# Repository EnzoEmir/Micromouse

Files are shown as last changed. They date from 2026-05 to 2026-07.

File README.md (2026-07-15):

# Micromouse — PI1 2026.1, Grupo 02

Projeto desenvolvido para a disciplina Projeto Integrador 1 (PI1) da FCTE/UnB. O desafio proposto pelos professores: projetar e construir, em equipes de até 20 integrantes, um robô Micromouse capaz de resolver labirintos 4x4 e 8x8 de forma **totalmente autônoma**, sem intervenção humana durante a corrida.

## O desafio

- Labirintos 4x4 e 8x8, com configuração de paredes definida pelos professores no dia da competição.
- Ponto de largada em um canto do labirinto, sorteado no momento da corrida.
- Cada célula do labirinto mede 18 cm de lado, com paredes de 1,2 cm de espessura.
- O objetivo é um bloco de 4 células (2x2) sem paredes entre si, no centro do labirinto.
- O robô precisa mapear o labirinto, alcançar esse bloco central e, em seguida, percorrê-lo pelo caminho mais curto conhecido.

## Estrutura do repositório

O projeto foi dividido em quatro núcleos: Eletrônica, Software, Estrutura e Energia. A organização de pastas segue o [template padrão do PI1](https://github.com/fcte-pi1/template):

| Pasta | Conteúdo |
|---|---|
| [`src/firmware`](src/firmware) | Firmware do Micromouse (ESP32/ESP-IDF): navegação, resolução de labirinto, controle de motores e sensores. |
| [`src/backend`](src/backend) | API (FastAPI) que recebe a telemetria do robô e persiste o histórico das corridas. |
| [`src/frontend`](src/frontend) | Interface web (React) para acompanhar o robô em tempo real durante a corrida. |
| [`hw`](hw) | Esquemáticos, PCBs e datasheets dos componentes eletrônicos. |
| [`mec`](mec) | Modelagem 3D, desenhos técnicos e montagem do chassi e do labirinto. |
| [`docs`](docs) | Documentação do projeto: EAP, relatório técnico, análise de riscos e seleção de componentes. |

## Minha participação

Atuei como **gerente de projeto** e como membro do **núcleo de Eletrônica**, focado no firmware do robô. Minhas principais responsabilidades técnicas foram:

- Firmware de navegação e resolução de labirinto (algoritmo flood-fill), em `src/firmware`.
- Calibração dos sensores (ToF, giroscópio/IMU, encoders) usados na navegação.
- Comunicação do robô com o sistema web (telemetria via Wi-Fi/HTTP durante a corrida).

Como gerente de projeto, coordenei a comunicação entre os quatro núcleos (Eletrônica, Software, Estrutura e Energia), priorizando e sincronizando as atividades que dependiam de mais de um núcleo para reduzir gargalos entre as equipes.

## Fluxo de execução do firmware

O `app_main` do firmware (`teste_navegacao.cpp`) segue, em cada corrida, a seguinte sequência:

1. **Inicialização de hardware** — sobe o barramento I2C (bateria/INA226), inicializa os 3 sensores ToF usados (frontal, esquerda, direita), o giroscópio (MPU9250), os encoders (via PCNT) e os motores. A conexão Wi-Fi é disparada em background, sem bloquear o boot.
2. **Seleção de largada** — com o robô parado, toques curtos no botão único alternam entre as combinações de tamanho do labirinto (4x4/8x8) e lado de largada (esquerda/direita); segurar o botão (≥ 0,7 s) confirma a seleção, calibra o bias do giroscópio e dá a largada.
3. **Envio da configuração inicial e heartbeat** — envia o pacote de configuração (tipo 0) ao backend, se o Wi-Fi já estiver conectado, e inicia uma tarefa paralela que envia heartbeats (tipo 4) periodicamente até o fim da execução.
4. **Mapeamento** — a cada célula, lê as paredes com os sensores ToF e avança um passo da máquina de estados do labirinto (flood-fill), que decide a direção e aciona os comandos de giro/avanço do robô. Cada nova célula descoberta é reportada ao backend (tipo 1). O mapeamento só termina após visitar todas as células alcançáveis do bloco 2x2 central (confirmando que o objetivo está aberto e foi de fato alcançado) ou, em caso de bloqueio, envia o pacote de fim de corrida (tipo 3) com falha.
5. **Corrida rápida (fast run)** — após o mapeamento, o robô é reposicionado manualmente na largada; um novo aperto do botão envia a rota ótima calculada (tipo 2) e inicia a corrida rápida, que percorre o labirinto pelo caminho mais curto conhecido, otimizando trechos retos em uma única execução contínua. Ao concluir, envia o pacote de fim de corrida (tipo 3) com sucesso e a velocidade média.
6. **Monitoramento contínuo** — em paralelo às fases acima, a temperatura é verificada a cada passo; se ultrapassar o limiar crítico, a corrida é abortada, os motores são parados e os pacotes de alerta (tipo 5) e fim de corrida (tipo 3, sem sucesso) são enviados.

## Demonstração

Vídeo da execução completa no labirinto 8x8: https://youtu.be/1a2v_xoSXcU

<p>
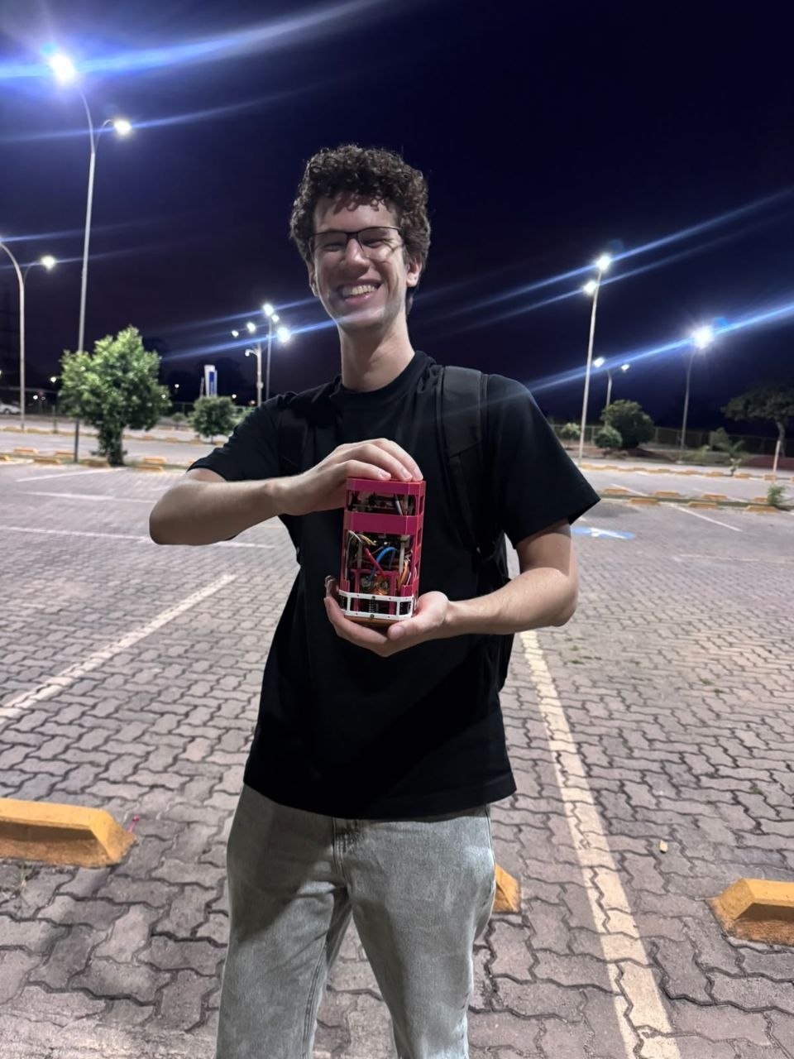
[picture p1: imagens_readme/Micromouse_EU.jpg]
Eu segurando o Micromouse
  
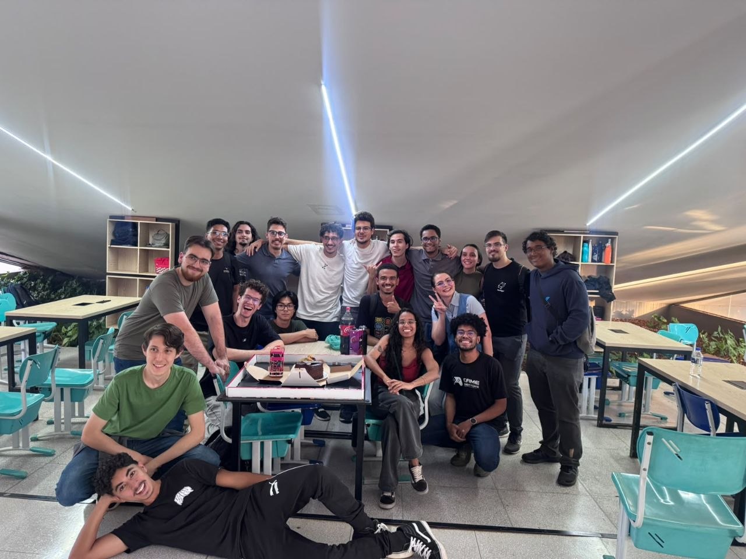
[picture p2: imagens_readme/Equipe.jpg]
Equipe do projeto
  
</p>

## Sobre este fork

Este repositório é um fork do projeto original de equipe, mantido para referência pessoal do trabalho realizado. Mais detalhes sobre a implementação do firmware estão em [`src/firmware`](src/firmware).

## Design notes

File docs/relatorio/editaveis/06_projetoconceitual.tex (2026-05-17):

\chapter{Projeto Conceitual do Produto}

\section{Características gerais}

\textcolor{red}{Descrever produto de forma geral. Apresentar itens teóricos sobre o projeto a serem aprofundados ou detalhados oportunamente.}

\textcolor{red}{Apresentar e explicar a Estrutura Analítica do Projeto (EAP), tomando cuidado com a legibilidade da imagem. Se necessário, coloque a EAP dentro do comando ``\textsf{\textbackslash begin\{landscape\} \textbackslash end\{landscape\}}'' para que ela seja apresentada em uma página deitada.}

\section{Estrutura}

\textcolor{red}{Apresentar desenho em CAD, indicar dimensões por lado/aresta/cota, indicar materiais utilizados e explicar o desenho e as decisões de projeto.}

\section{Descrição de \textit{hardware}}

\textcolor{red}{A descrição de \textit{hardware} no documento deve permitir que outras pessoas repliquem o produto proposto neste documento. Para isso, deve-se explicar de forma textual os principais sub-sistemas e as escolhas de projeto, além de indicar:}

\begin{itemize}
    \item \textcolor{red}{ O diagrama de blocos \cite{blockdiagram}, que oferece uma visão geral do hardware, com as principais partes do sistema e as ligações entre elas.}
    %\item A lista de materiais \cite{bom}, que facilita a montagem do sistema, indicando tudo que deve ser adquirido. Aproveitem a lista de materiais para apresentarem o orçamento dos mesmos.
    \item \textcolor{red}{ O esquemático \cite{esquematico}, que mostra as conexões elétricas entre os componentes. Deve-se indicar os componentes por nomes e símbolos, e as conexões entre eles, incluindo a pinagem dos componentes. Se o esquemático ficar muito grande, pode-se separa-lo em vários esquemáticos. A ligação em \textit{protoboard} não é considerada um esquemático adequado.}
\end{itemize}

\textcolor{red}{A Fig. \ref{fig:diagrama_blocos_e_esquematico} apresenta o diagrama de blocos e o esquemático de um circuito conversor de corrente alternada para corrente direta, a título de exemplo. Repare que o diagrama de blocos indica os subsistemas do circuito completo apresentado no esquemático.
% Comecem com o diagrama de blocos, que é mais genérico, e depois indiquem os detalhes com a lista de materiais e os esquemáticos.
}

\begin{figure}
    \centering
    
    
    \caption{\textcolor{red}{Diagrama de blocos e esquemático de um circuito conversor de corrente alternada para corrente direta. Extraído de \cite{block_n_schematic}.}}
    \label{fig:diagrama_blocos_e_esquematico}
\end{figure}

\section{Análise de consumo energético}

\subsection{Identificação dos Subsistemas Elétricos}
\label{sec:identificacao_subsistemas}

A identificação dos subsistemas elétricos foi realizada com base nos componentes que consumirão energia durante a operação do micromouse, incluindo sensores, microcontroladores, atuadores, módulos de armazenamento e circuitos de suporte. Para fins de dimensionamento, foi adotado um tempo estimado de uso de 7200\,s, correspondente a uma missão de aproximadamente 2 horas. Os valores de tensão e corrente média foram obtidos a partir de \textit{datasheets} sempre que disponíveis, ou por estimativas conservadoras baseadas em condições realistas de operação.

\begin{table}[htbp]
    \centering
    \caption{Identificação dos subsistemas elétricos e parâmetros de operação}
    \label{tab:subsistemas_eletricos}

    \renewcommand{\arraystretch}{1.2}

    \begin{tabular}{lcccc}
        \hline
        \textbf{Componente} &
        \textbf{Qtde} &
        \textbf{Tensão (V)} &
        \textbf{Corrente média (mA)} &
        \textbf{Tempo (s)} \\
        \hline

        ESP32 & 1 & 3,3 & 200 & 7200 \\
        VL53L0X & 6 & 3,3 & 20 & 7200 \\
        Motor N20 (6V) & 2 & 6,0 & 400 & 7200 \\
        Driver (TB6612) & 1 & 3,3 & 30 & 7200 \\
        MPU6050 & 1 & 3,3 & 4 & 7200 \\
        INA226 & 1 & 3,3 & 0,33 & 7200 \\
        SD Reader & 1 & 3,3 & 80 & 7200 \\
        Regulador (MP1584EN) & 1 & 3,3 & 100 & 7200 \\
        Outros (LEDs, perdas) & -- & 3,3 & 100 & 7200 \\

        \hline
    \end{tabular}
\end{table}

Os valores apresentados na Tabela~\ref{tab:subsistemas_eletricos} contemplam os principais elementos energizados do sistema.

\subsection{Cálculo da Energia Consumida por Componente}
\label{sec:calculo_energia_componente}

A energia consumida por cada componente foi calculada por meio da expressão:

\begin{equation}
E = V \cdot I \cdot t
\end{equation}

em que $E$ representa a energia em joules, $V$ a tensão em volts, $I$ a corrente em ampères e $t$ o tempo de uso em segundos. Para os cálculos, as correntes em miliampères foram convertidas para ampères.

A seguir, apresenta-se o detalhamento da energia consumida por cada subsistema, cujos valores estão sintetizados na Tabela~\ref{tab:energia_por_componente}.

\begin{table}[htbp]
    \centering
    \caption{Energia consumida por componente}
    \label{tab:energia_por_componente}

    \renewcommand{\arraystretch}{1.2}

    \begin{tabular}{lc}
        \hline
        \textbf{Componente} & \textbf{Energia (J)} \\
        \hline

        ESP32 & 4752,00 \\
        VL53L0X & 2851,20 \\
        Motor N20 (2 unidades) & 34560,00 \\
        Driver (TB6612) & 712,80 \\
        MPU6050 & 95,04 \\
        INA226 & 7,84 \\
        SD Reader & 1900,80 \\
        Regulador (MP1584EN) & 2376,00 \\
        Outros (LEDs, perdas) & 2376,00 \\

        \hline
        \textbf{Total} & \textbf{49631,68} \\
        \hline
    \end{tabular}
\end{table}

\subsection{Estimativa do Consumo Total de Energia}
\label{sec:consumo_total_energia}

A energia total estimada por lançamento corresponde à soma das energias individuais dos subsistemas listados anteriormente:

\begin{equation}
E_{\text{total}}
=
4752{,}00 + 2851{,}20 + 34560{,}00 + 712{,}80 + 95{,}04 + 7{,}84 + 1900{,}80 + 2376{,}00 + 2376{,}00
\end{equation}

\begin{equation}
E_{\text{total}}
=
49631{,}68\,\mathrm{J}
\end{equation}

Para expressar esse consumo em watt-hora, utiliza-se a relação:

\begin{equation}
1\,\mathrm{Wh} = 3600\,\mathrm{J}
\end{equation}

Logo, a conversão do consumo total é dada por:

\begin{equation}
E_{\text{total,Wh}}
=
\frac{49631{,}68}{3600}
\approx
13{,}79\,\mathrm{Wh}
\end{equation}

Também é possível estimar a corrente média total do sistema a partir da soma das correntes nominais:

\begin{equation}
I_{\text{nom}}
=
200 + 120 + 800 + 30 + 4 + 0{,}33 + 80 + 100 + 100
=
1434{,}33\,\mathrm{mA}
\end{equation}

Portanto,

\begin{equation}
I_{\text{nom}}
\approx
1{,}434\,\mathrm{A}
\end{equation}

Para tornar o dimensionamento mais robusto, foi aplicada uma margem de segurança de 40\%, a fim de contemplar variações de carga, perdas não modeladas e oscilações durante a operação:

\begin{equation}
I_{\text{proj}}
=
I_{\text{nom}} \times 1{,}4
\end{equation}

Substituindo-se o valor obtido:

\begin{equation}
I_{\text{proj}}
=
1{,}434 \times 1{,}4
\approx
2{,}01\,\mathrm{A}
\end{equation}

Em seguida, considerou-se um fator de utilização de 70\%, uma vez que nem todos os subsistemas operam continuamente em máxima corrente durante toda a missão:

\begin{equation}
I_{\text{real}}
=
I_{\text{proj}} \times 0{,}7
\end{equation}

Assim,

\begin{equation}
I_{\text{real}}
=
2{,}01 \times 0{,}7
\approx
1{,}41\,\mathrm{A}
\end{equation}

A capacidade mínima da bateria pode ser estimada por:

\begin{equation}
C_{\text{min}}
=
I_{\text{real}} \times t
\end{equation}

Para uma autonomia de 2 horas:

\begin{equation}
C_{\text{min}}
=
1{,}41 \times 2
=
2{,}82\,\mathrm{Ah}
\approx
2820\,\mathrm{mAh}
\end{equation}

Para uma autonomia de 3 horas:

\begin{equation}
C_{\text{min}}
=
1{,}41 \times 3
=
4{,}23\,\mathrm{Ah}
\approx
4230\,\mathrm{mAh}
\end{equation}

\subsection{Escolha da Fonte de Alimentação}
\label{sec:escolha_fonte}

Com base no consumo energético total estimado, a demanda por lançamento é de aproximadamente 13,79\,Wh. Considerando uma margem de segurança adicional de 25\%, obtém-se uma demanda projetada de aproximadamente 17,24\,Wh.

\begin{equation}
E_{\text{proj,Wh}}
=
13{,}79 \times 1{,}25
\approx
17{,}24\,\mathrm{Wh}
\end{equation}

A fonte de alimentação selecionada é um conjunto formado por duas células idênticas em série do modelo N21700CG-50 da BAK Battery. Considerando as especificações típicas informadas, cada célula possui tensão nominal de 3,6\,V e capacidade de 5,0\,Ah. Em série, o conjunto passa a fornecer tensão nominal de 7,2\,V, mantendo a capacidade de 5,0\,Ah.

A energia nominal do conjunto é dada por:

\begin{equation}
E_{\text{bat}}
=
7{,}2 \times 5{,}0
=
36\,\mathrm{Wh}
\end{equation}

Esse valor é superior à demanda projetada de 17,24\,Wh, oferecendo folga energética suficiente para o funcionamento do robô.

Como os motores são nominais de 6\,V, o barramento principal será tratado como a alimentação de potência do sistema, enquanto os blocos de lógica, sensores e microcontrolador serão alimentados com tensão regulada pelo MP1584EN para 3,3\,V.

A tabela a seguir resume a escolha da fonte.

\begin{table}[htbp]
    \centering
    \caption{Resumo da fonte de alimentação selecionada}
    \label{tab:fonte_alimentacao}

    \renewcommand{\arraystretch}{1.2}

    \begin{tabular}{lccc}
        \hline
        \textbf{Fonte} & \textbf{Tensão nominal} & \textbf{Capacidade} & \textbf{Energia} \\
        \hline
        2 células em série & 7,2\,V & 5,0\,Ah & 36\,Wh \\
        \hline
    \end{tabular}
\end{table}

subsubsection{Síntese do dimensionamento}

Com base nos cálculos apresentados, o sistema possui consumo energético estimado de 49\,631,68\,J por lançamento, equivalente a aproximadamente 13,79\,Wh. Após aplicação de margem de segurança de 25\%, a demanda projetada passa a ser de aproximadamente 17,24\,Wh.

A fonte selecionada, composta por duas células em série, fornece aproximadamente 36\,Wh, o que atende confortavelmente à demanda do projeto. Dessa forma, a solução escolhida supre a necessidade energética do micromouse e oferece margem adequada para picos de corrente, perdas de conversão e variações operacionais.

Ressalta-se que a corrente dos motores foi considerada em regime nominal de operação, e não em condição de \textit{stall}, evitando superdimensionamento excessivo do sistema de alimentação.

\subsection{Planejamento do Circuito de Alimentação}
\label{sec:planejamento_circuito_alimentacao}

O circuito de alimentação será organizado em dois blocos: potência e lógica. O barramento principal, derivado das duas células em série, alimenta a etapa de potência, enquanto o regulador MP1584EN reduz a tensão para 3,3\,V na etapa lógica.

Para reduzir oscilações de tensão e interferências entre os subsistemas, serão adotadas as seguintes medidas:
\begin{itemize}
    \item uso de regulador buck para a linha de 3,3\,V;
    \item capacitores de desacoplamento próximos aos circuitos integrados;
    \item capacitor de bulk na entrada do sistema;
    \item separação física e elétrica entre alimentação dos motores e da lógica;
    \item uso do driver TB6612 como interface entre ESP32 e motores.
\end{itemize}

A INA226 será utilizada apenas para monitoração de corrente, tensão e potência, permitindo acompanhar o comportamento energético em tempo real. Assim, a estabilidade do sistema será garantida pela combinação entre regulação adequada, desacoplamento e separação das linhas de alimentação.

\section{Referências dos Datasheets}
\label{sec:referencias}

\begin{itemize}

    \item ESP32 -- Espressif Systems. \textit{ESP32 Series Datasheet}. Disponível em:
    \url{https://www.espressif.com/sites/default/files/documentation/esp32_datasheet_en.pdf}

    \item VL53L0X -- STMicroelectronics. \textit{VL53L0X Time-of-Flight Ranging Sensor Datasheet}. Disponível em:
    \url{https://www.st.com/resource/en/datasheet/vl53l0x.pdf}

    \item MPU6050 -- InvenSense. \textit{MPU-6000 and MPU-6050 Product Specification}. Disponível em:
    \url{https://invensense.tdk.com/wp-content/uploads/2015/02/MPU-6000-Datasheet1.pdf}

    \item TB6612FNG -- Toshiba. \textit{TB6612FNG Dual H-Bridge Motor Driver Datasheet}. Disponível em:
    \url{https://toshiba.semicon-storage.com/info/docget.jsp?did=10660}

    \item MP1584EN -- Monolithic Power Systems. \textit{MP1584 3A Step-Down Converter Datasheet}. Disponível em:
    \url{https://www.monolithicpower.com/en/documentview/productdocument/index/version/2/document_type/Datasheet/lang/en/sku/MP1584EN-LF-Z/document_id/221}

    \item INA226 -- Texas Instruments. \textit{INA226 Current/Power Monitor Datasheet}. Disponível em:
    \url{https://www.ti.com/lit/ds/symlink/ina226.pdf}

    \item BAK N21700CG-50 -- BAK Battery. \textit{Product Data Sheet}. Especificações consideradas: tensão nominal de 3,6\,V, capacidade típica de 5,0\,Ah, tensão máxima de carga de 4,2\,V, tensão final de descarga de 2,5\,V, corrente padrão de carga de 0,5C e corrente máxima de descarga de 3C.

    \item Motor N20 6V -- Especificações obtidas a partir do modelo comercial adquirido, complementadas por valores típicos de motores N20 equivalentes utilizados em aplicações embarcadas.

\end{itemize}

\section{Descrição de \textit{software}}

\textcolor{red}{Itens fundamentais:}

\begin{itemize}
    \item \textcolor{red}{ \textbf{Diagrama BPMN para entender o \textit{software} proposto:} deve deixar claro os principais atores do sistema, suas atividades (de negócios), insumos e resultados.}
    \item \textcolor{red}{\textbf{\textit{Backlog} funcional do \textit{software}:}}
    \begin{itemize}
        \item \textcolor{red}{ Escrito no formato de histórias de usuário ou casos de uso (decisão da equipe);}
        \item \textcolor{red}{ Ao declarar o \textit{backlog} de requisitos funcionais, usar a  classificação de MoSCoW (\textit{Must have}, \textit{Should have} e \textit{Could have}),  para um melhor entendimento do próprio \textit{backlog}.}
    \end{itemize}
    \item \textcolor{red}{\textbf{ \textit{Backlog} não-funcional do \textit{software}:}}
    \begin{itemize}
        \item \textcolor{red}{ Descrever os requisitos não-funcionais de forma objetiva;}
        \item \textcolor{red}{ Mais facilmente, mais rapidamente, são descrições subjetivas não-válidas. Um exemplo de requisito não-funcional de desempenho: ``a página deve carregar em até 5s quando em conexão 4G''. }
    \end{itemize}
    \item \textcolor{red}{ \textbf{Diagrama de casos de uso,} contendo os atores do sistema, os requisitos com os quais eles interagem e os tipos de relacionamentos entre requisitos realizados por um mesmo ator (ex.: \textit{include}, \textit{extend}). Obs.: este é um diagrama sobre requisitos funcionais.}
    \item \textcolor{red}{ \textbf{Descrição da arquitetura da solução de \textit{software} proposta:}}
    \begin{itemize}
        \item \textcolor{red}{ Propósito do \textit{software} (qual o seu papel no sistema);}
        \item \textcolor{red}{ Estilo arquitetural contendo:}
        \begin{itemize}
            \item \textcolor{red}{ Padrão adotado: MVC, MVP, Microsserviços, Monolítico, etc (Justificar);}
            \item \textcolor{red}{ Linguagens de programação: Java, Python, C\#, JavaScript, etc.}
            \item \textcolor{red}{ \textit{Frameworks} e bibliotecas: Spring Boot, .NET Core, React, Angular, Django, etc.}
            \item \textcolor{red}{ Banco de dados: Relacional (PostgreSQL, MySQL, etc) X NãoSQL (MongoDB,etc). }
        \end{itemize}
        \item \textcolor{red}{ Diagrama de alto nível: representação esquemática dos componentes da arquitetura, suas responsabilidades e comunicações, esclarecendo a composição do \textit{front-end} e do \textit{back-end}.}
    \end{itemize}
    \item \textcolor{red}{ \textbf{Persistência de dados:} diagrama de entidade relacionamento do banco de dados usado na solução proposta.}
    \item \textcolor{red}{ \textbf{Análise de dados:} as variáveis definidas nos requisitos do projeto em abordagem numérica e gráfica.}
    \item \textcolor{red}{ \textbf{Diagrama de estados} esclarecendo os estados assumidos pelo \textit{software} e os eventos que causam as mudanças de estado do \textit{software}.}
    \item \textcolor{red}{ \textbf{Protótipo funcional do \textit{software}, navegável.}}
    \item \textcolor{red}{\textbf{ Roteiro de testes funcionais:} }
    \begin{itemize}
        \item \textcolor{red}{Código do caso de teste;}
        \item \textcolor{red}{Nome do caso de teste;}
        \item \textcolor{red}{Tipo do caso de teste (unitário, integrado ou sistema);}
        \item \textcolor{red}{ Objetivo do caso de teste;}
        \item \textcolor{red}{ Pré-condições do sistema para o teste ser realizado;}
        \item \textcolor{red}{ Descrição dos procedimentos a serem executados para o teste;}
        \item \textcolor{red}{ Resultado esperado para o teste ser aprovado (pós-condição após realizado o teste);}
        \item \textcolor{red}{ Especificação do reparo a ser executado (caso o teste não seja aprovado);}
        \item \textcolor{red}{ Resultado após reparo (o caso do teste ser necessário de ser repetido após reparo).}
    \end{itemize}
\end{itemize}

% \textcolor{red}{Com relação ao \textit{software}, será necessário apresentar os seguintes itens: % pacotes de componentes de \textit{software}, suas funções e características, e explicar as decisões de projeto:
% \begin{enumerate}
%     \item Um diagrama do processo de negócio do problema que a máquina se propõe a resolver (BPNM) – não é UML, mas é fundamental para entender como o sistema se comporta como um todo, incluindo o usuário;
%     \item Lista de casos de uso (backlog do sistema). Backlog funcional;
%     \item Lista de requisitos não-funcionais a serem satisfeitos pelo sistema;
%     \item Diagrama de casos de uso: mostrando os requisitos funcionais, seus atores e como eles interagem entre si;
%     \item Diagrama de Classes: apresentando quais dados são manipulados pelo sistema (internamente e externamente – ex.: resultados de experimentos);
%     \item Diagrama de arquitetura, identificando todos os componentes da máquina e suas iterações com o software;
%     \item Diagrama de estados da máquina (sistema);
%     \item Descrição dos testes dos componentes da máquina e dos testes funcionais que deveriam ser feitos para avaliar o funcionamento da máquina e identificar defeitos. São importantes os testes unitários (componentes) e de integração (conjunto de componentes) e o roteiro de testes.
% \end{enumerate}
% }
%\textcolor{red}{Com relação ao \textit{software}, será necessário apresentar pacotes de componentes de \textit{software}, suas funções e características, e explicar as decisões de projeto.}

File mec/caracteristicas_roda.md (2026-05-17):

# Características da Roda e Pneu do Micromouse

## 1. Introdução

Nesse documento, estão descritas as características centrais e demais informações referentes ao modelo de roda (que inclui a roda interna e o pneu) selecionado para o projeto de micromouse, que possuirá duas rodas na parte de trás da carcaça e um deslizador (skid) na frente.

As características definidas foram baseadas em diversos fatores, os quais estão, em sua maioria, descritos na página [*Esboço de características desejáveis das rodas*](./mec/esboco_caracteristicas_desejaveis_rodas.md). Além disso, a escolha também foi influenciada pelo fato de integrantes da equipe se disporem a emprestar rodas que possuiam, com propriedades adequadas, para o projeto. Essa abordagem permite que o grupo corte o custo de compra das rodas, e dispensa o tempo necessário para a encomenda e entrega do produto.

<br>

## 2. Propriedades

### 2.1. Material

O pneu é composto de um **elastômero termoplástico (TPE)** chamado de **SBS** (*estireno-butadieno-estireno*). Esse material é conhecido pela sua flexibilidade, maciez e alta aderência, sendo essa última fundamental para o desejável alto atrito com o solo.

A roda interna, que já é moldada para o encaixe com o pneu, é feita de plástico  **ABS** (*Acrilonitrila Butadieno Estireno*), que possui boa durabilidade e resistência, além de sua leveza.

### 2.2. Dimensões

O pneu possui um diâmetro de *30 mm* e largura de *11 mm*. A roda interna, por sua vez, possui diâmetro de *17 mm* e largura de *7 mm*, além de um vão no seu eixo de 
diamêtro *4,5 mm*.

### 2.3. Textura da banda de rodagem

A textura da banda de rodagem é composta por uma linha central lisa com largura *1,94 mm*, e sulcos de comprimento *2,75 mm* em ambos os lados por toda a superfície.

Apesar de ser preferível uma superfície sem sulcos, para maximizar o atrito com a superfície lisa em *MDF*, a existência de sulcos não trará impactos negativos significantes para essa questão, dado o escopo e o contexto do projeto.

<br>

## 3. Desenhos Técnicos

Abaixo, estão apresentados os desenhos técnicos da roda interna e do pneu.

<p align="center"><i>Imagem 1:</i> Desenho técnico da Roda Interna</p>

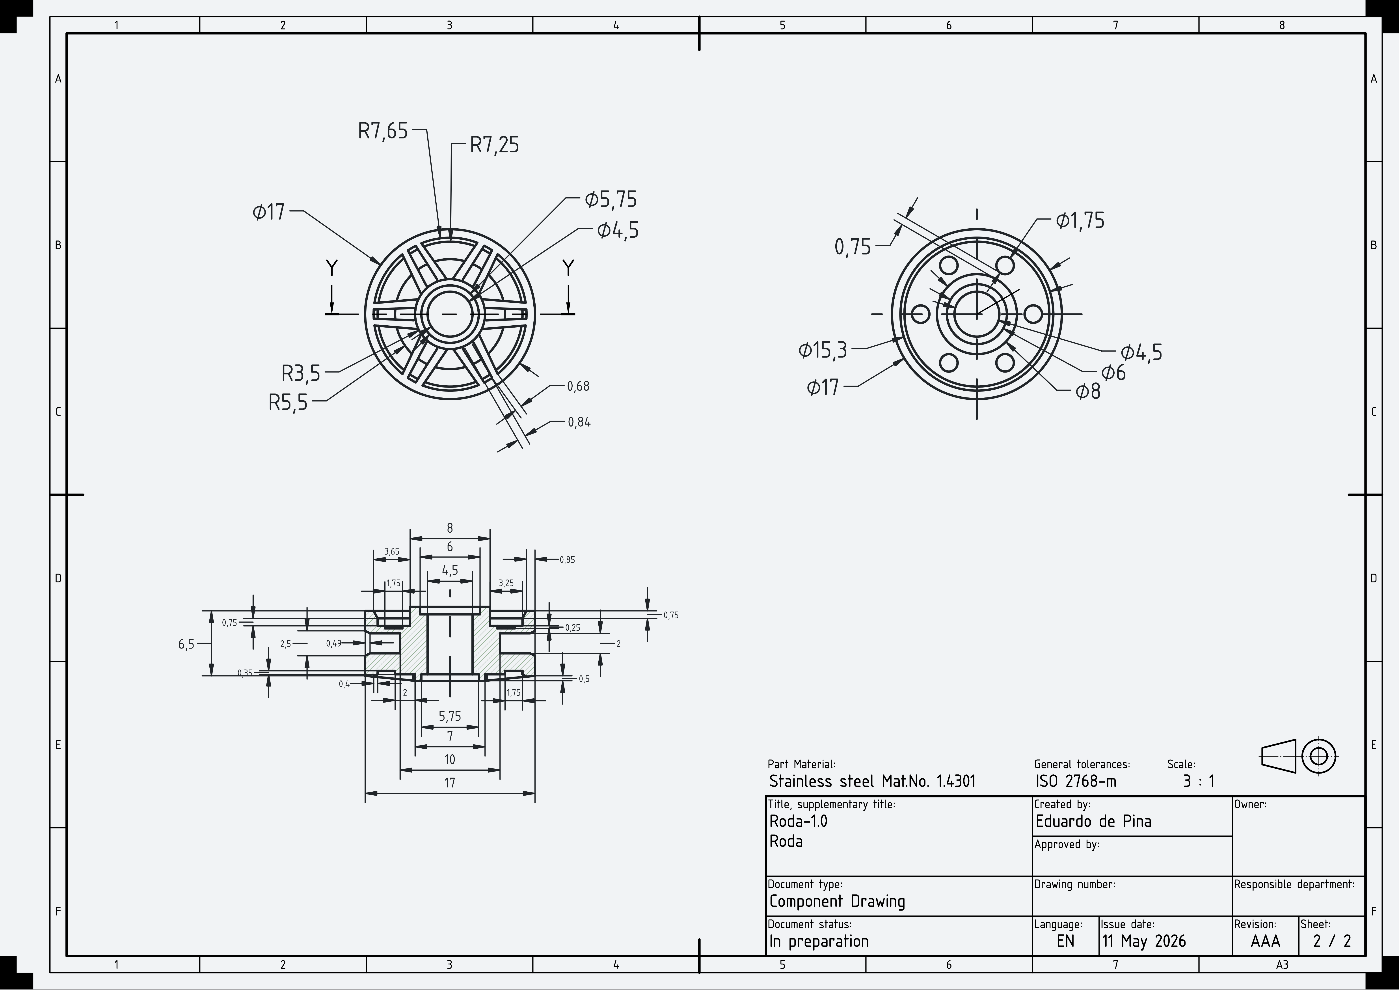
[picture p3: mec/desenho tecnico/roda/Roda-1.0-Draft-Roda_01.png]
Roda Interna


<p align="center"><b>Fonte: </b>Autoria de <a href="https://github.com/eduardodpms">Eduardo de Pina</a></p>

<br>

<p align="center"><i>Imagem 2:</i> Desenho técnico do Pneu</p>

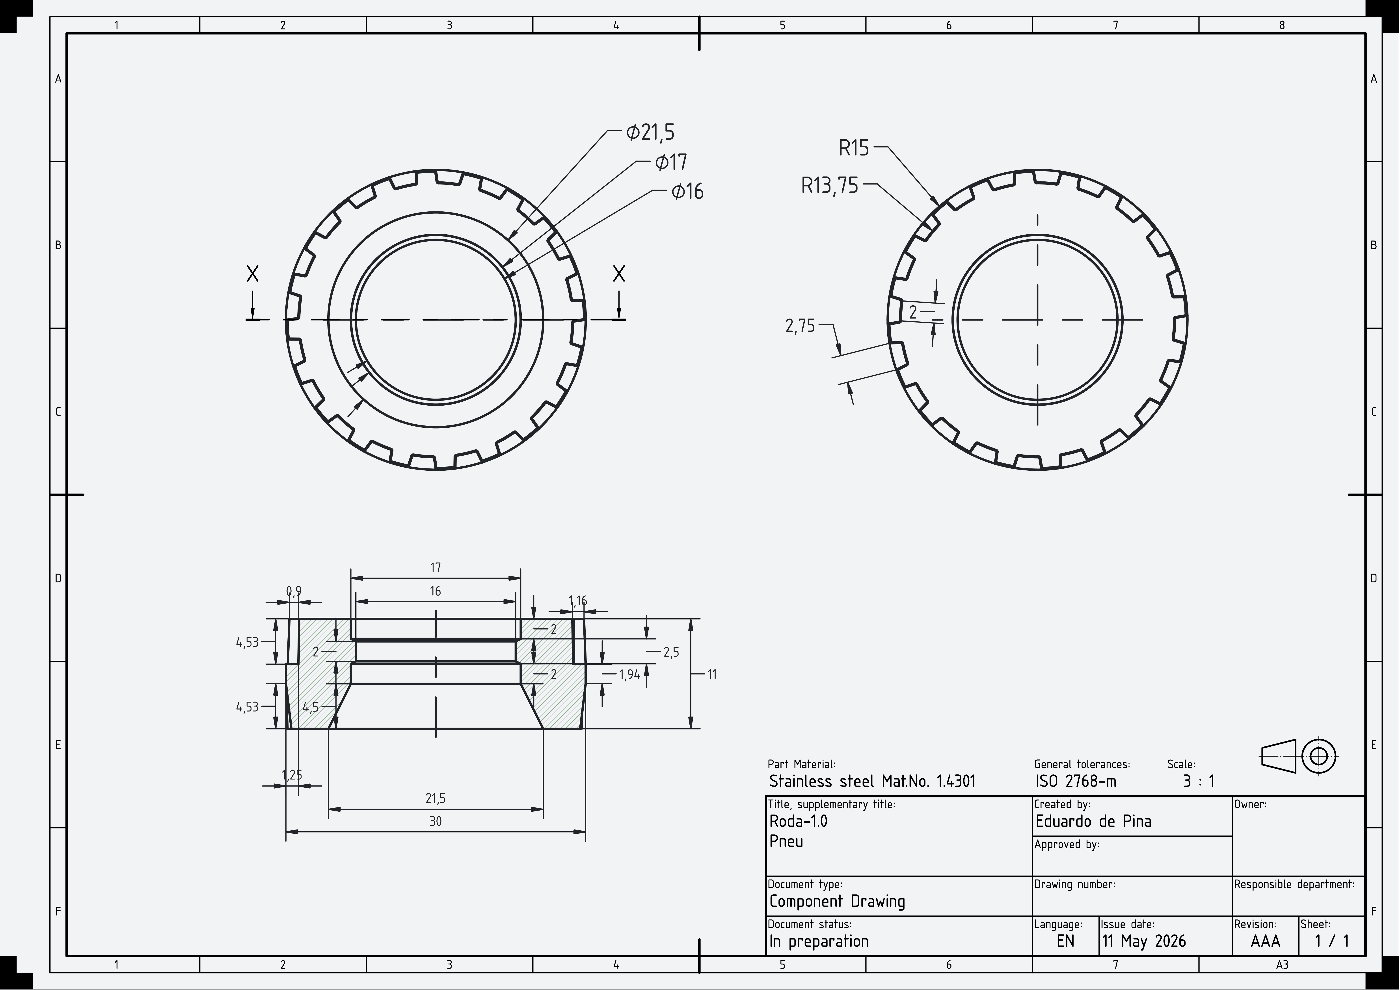
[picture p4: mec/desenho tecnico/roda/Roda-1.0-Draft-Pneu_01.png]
Pneu


<p align="center"><b>Fonte: </b>Autoria de <a href="https://github.com/eduardodpms">Eduardo de Pina</a></p>

<br>

## 4. Tabela de Versionamento

| Versão | Data | Autor | Descrição | Revisor |
| :-: | :-: | :-: | :-: | :-: |
| 1.0 | 12/05/2026 | [Eduardo de Pina](https://github.com/eduardodpms) | Criação do documento | [Giovanni Mateus](https://github.com/GiovanniMateus
) |

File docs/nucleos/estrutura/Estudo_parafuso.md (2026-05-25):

## Teste da fixação de duas placas impressas em impressão 3D por parafuso M2

Um dos problemas enfrentados na montagem do micromouse é garantir o uso adequado de parafusos M2 na fixação dos suportes estruturais, como base ao capô, skid à base, suporte dos sensores à base, suporte da PCB à base, suporte do motor à base e suporte do mancal à base. Para avaliar a viabilidade dessa fixação, foi desenvolvido um modelo simples composto por duas placas impressas em 3D para teste com parafusos M2.

Existem diferentes formas de utilizar parafusos M2 em peças impressas. A impressão direta de roscas no plástico é, em geral, inviável para impressoras FDM comuns. A rosca de um parafuso M2 possui diâmetro nominal de 2 mm e passo de 0,4 mm, ficando próxima do limite de resolução de impressoras equipadas com bicos de 0,4 mm, como a Ender-3 Pro. A impressão da rosca fêmea diretamente na peça tende a resultar em falhas geométricas, emperramento do parafuso ou baixa resistência mecânica da região roscada. Assim, as alternativas mais viáveis são o uso de porcas inseridas na peça ou a utilização do próprio parafuso para autoatarraxamento no plástico.

O modelo utilizado está disponível em `/mec/modelagem 3d/testes`. O teste inclui furos com diâmetros entre 2,0 mm e 2,4 mm, além de alojamentos para porcas com dimensões entre 4,0 mm e 4,4 mm.

Imagem do modelo em FreeCAD

Nos testes realizados, observou-se que o parafuso M2 não conseguiu ser inserido em furos de 2,2 mm produzidos pela impressora Ender-3 Pro. Em contrapartida, os furos de 2,3 mm e 2,4 mm permitiram o autoatarraxamento do parafuso, possibilitando a fixação adequada entre as duas placas. Também foi observado que alojamentos de 4,4 mm ainda não permitem o encaixe adequado da porca, sendo necessário testar dimensões a partir de 4,5 mm.

### Tabela 1 — Resultado dos testes de fixação com parafuso M2

| Elemento testado | Dimensão nominal | Resultado observado | Observação |
| --- | ---: | --- | --- |
| Furo passante/atarraxamento | 2,0 mm | Não compatível | Parafuso não entra |
| Furo passante/atarraxamento | 2,2 mm | Não compatível | Parafuso não entra na peça impressa pela Ender-3 Pro |
| Furo passante/atarraxamento | 2,3 mm | Compatível | Permite autoatarraxamento |
| Furo passante/atarraxamento | 2,4 mm | Compatível | Permite autoatarraxamento com menor esforço |
| Alojamento para porca M2 | 4,0 mm | Não compatível | Espaço insuficiente para encaixe |
| Alojamento para porca M2 | 4,4 mm | Parcialmente compatível | Ainda não permite encaixe adequado |
| Alojamento para porca M2 | ≥ 4,5 mm | Não testado | Dimensão recomendada para testes futuros |

**Legenda:** Resultados obtidos a partir de testes de fixação utilizando parafusos M2 em peças impressas em PLA na impressora Ender-3 Pro. Os ensaios avaliaram tanto o autoatarraxamento do parafuso em furos impressos quanto o encaixe de porcas sextavadas M2 em alojamentos dedicados.

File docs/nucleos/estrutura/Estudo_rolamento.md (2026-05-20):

# Justificativa do uso de rolamento no eixo da roda do micromouse

A utilização de rolamento no eixo da roda do micromouse é a solução considerada adequada para o projeto, pois esse componente reduz o atrito no sistema, melhora o alinhamento do eixo e contribui para um movimento mais estável e preciso. Como o micromouse precisa realizar acelerações, frenagens e curvas em certa velocidade, é importante que as rodas girem com a menor resistência possível, evitando perdas mecânicas e melhorando o aproveitamento do torque do motor.

Além disso, o projeto utilizará engrenagens retas na transmissão. Nesse tipo de engrenagem, os dentes são paralelos ao eixo e o bom funcionamento depende de alinhamento correto entre os eixos, contato adequado entre os dentes e controle de folgas durante a rotação. Por isso, a engrenagem maior acoplada à roda precisa de um suporte firme e preciso, capaz de manter sua posição e evitar desalinhamentos que possam gerar vibração, ruído, desgaste prematuro e perda de eficiência na transmissão .

Nesse contexto, o rolamento exerce papel importante porque fornece apoio adequado ao eixo da roda e à engrenagem maior, mantendo o conjunto mais estável durante o funcionamento. Esse suporte ajuda a preservar o engrenamento correto entre pinhão e engrenagem, reduzindo oscilações no eixo e melhorando a repetibilidade do movimento, algo essencial para o desempenho do micromouse em trajetórias curtas e manobras rápidas .

Dessa forma, a escolha do rolamento se justifica tanto pela redução de atrito quanto pela necessidade de oferecer suporte adequado ao eixo e à engrenagem maior da roda, assegurando melhor funcionamento da transmissão por engrenagens retas e maior precisão no deslocamento do robô.

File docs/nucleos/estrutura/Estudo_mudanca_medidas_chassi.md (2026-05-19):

# Redimensionamento do Chassi e Organização dos Componentes

Devido ao tamanho total da área da célula em que o micromouse irá passar (16,8 cm), a estrutura do chassi precisará ser remodelada. O tamanho atual, de 94 mm de largura por 94 mm de altura (90 mm x 90 mm de espaço interno e 2 mm de espessura das “paredes”), não se comporta adequadamente para o espaço que a célula possui.

## Organização das PCBs

Em relação à PCB, foi acordado com toda a equipe que será necessário o uso de duas placas de 6 cm x 6 cm (ou 6,5), posicionadas uma sobre a outra de forma paralela, utilizando espaçadores.

## Redimensionamento da Área da Bateria

Em relação à bateria, que possui as dimensões de 7 cm x 4 cm x 3 cm, ela foi a parte mais difícil no processo de redimensionamento da carcaça, pois precisa permanecer alocada na horizontal. Caso fosse posicionada na vertical, ocuparia muito espaço, fazendo com que encostasse nos motores e nos sensores.

Existia também a possibilidade de deixá-la em pé, mas, considerando os piores casos em que a bateria não esteja bem encaixada, ela poderia cair para a parte frontal, danificando os sensores, ou para a parte traseira, danificando as placas, que são muito frágeis.

## Novo Dimensionamento do Chassi

Dito isso, um bom redimensionamento para o chassi seria deixá-lo com 7,5 cm x 7,5 cm, pois, de acordo com o cálculo da sobra em relação às paredes de cada lado:

(16,8 - (7,5 × √2)) / 2

teríamos aproximadamente 3 cm de distância das paredes em cada lado.

Sendo assim, nenhum dos componentes citados anteriormente interferiria nos demais, mantendo um espaço seguro para que todos possam exercer suas funções adequadamente, além de garantir uma distância segura das paredes.

## Alteração no Suporte da Bateria

Outro ponto levantado e estudado pelo grupo de estruturas foi a mudança do suporte da bateria.

Na área demarcada para a bateria, haverá uma espessura maior, e serão confeccionados dois encaixes com furos para parafusos, que ficarão alocados nas extremidades da bateria.

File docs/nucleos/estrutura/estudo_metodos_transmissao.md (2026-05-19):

# Estudo sobre métodos de transmissão da roda no motor

## 1. Objetivo

Esta pesquisa compara métodos de  transmissão entre motor e roda para o micromouse, com foco em uma solução que seja simples de montar, confiável e adequada ao CAD do chassi.

## 2. Métodos avaliados

### 2.1 Roda direta no eixo do motor N20

Nesta opção, a roda é encaixada diretamente no eixo de saída do motor N20. Como o N20 já possui redução interna, o sistema fica mais simples:

```text
motor N20 com redução → roda encaixada diretamente no eixo
```

**Vantagens:**

- Menor quantidade de peças.
- Não precisa alinhar engrenagens externas.
- Não precisa tensionar correia.
- Menor chance de folga, travamento ou erro no CAD.
- Boa opção para garantir uma versão funcional do robô.

**Desvantagens:**

- Menor liberdade para alterar mecanicamente a relação de velocidade/torque.
- Se a roda for muito grande, o robô pode ficar rápido demais.
- Depende de encontrar roda compatível com eixo tipo D de 3 mm.

### 2.2 Engrenagens retas externas

Nesta opção, usa-se um pinhão pequeno no eixo do motor e uma engrenagem maior no eixo da roda:

```text
motor → pinhão pequeno → engrenagem maior → eixo da roda → roda
```

**Vantagens:**

- Permite aumentar o torque na roda.
- Permite reduzir a velocidade mecanicamente.
- Permite testar o chassi com um eixo de roda separado.
- É simples de explicar e pode ser fabricada ou comprada com peças de robótica.

**Desvantagens:**

- Exige alinhamento preciso entre pinhão, engrenagem maior e eixo da roda.
- Precisa de suporte para o eixo da roda, preferencialmente com bucha ou rolamento.
- Aumenta o número de peças e o risco de folga ou travamento.
- Os dois lados precisam ficar praticamente iguais para o robô não puxar para um lado.

### 2.3 Polias com correia GT2

Nesta opção, uma polia no motor transmite movimento para uma polia na roda usando correia dentada GT2:

```text
motor → polia pequena → correia GT2 → polia maior → eixo da roda → roda
```
**Vantagens:**

- transmissão mais suave e silenciosa;
- permite deixar o motor mais afastado da roda;
- reduz o contato direto entre engrenagens;
- permite alterar a relação de velocidade/torque trocando as polias;
- é comum em projetos de robótica e impressoras 3D.

**Desvantagens:**

- precisa de tensionamento correto da correia;
- se a correia ficar frouxa, pode pular dente;
- se ficar apertada demais, aumenta o atrito e pode forçar o motor;
- exige mais cuidado no CAD para prever ajuste de tensão;
- pode ocupar mais espaço no chassi.

---

## 3. Comparação das opções

| Critério | Roda direta no N20 | Engrenagens retas | Correia GT2 | Melhor para o grupo |
|---|---|---|---|---|
| Facilidade de montagem | Alta | Média | Média/baixa | Roda direta |
| Número de peças | Baixo | Médio | Médio/alto | Roda direta |
| Risco de desalinhamento | Baixo | Médio/alto | Médio | Roda direta |
| Ajuste de torque mecânico | Baixo | Bom | Bom | Engrenagens/GT2 |
| Necessidade de tensionamento | Não | Não | Sim | Roda direta/engrenagens |
| Chance de funcionar rápido | Alta | Média | Média/baixa | Roda direta |

---

## 4. Método escolhido: engrenagens retas

O método escolhido será a **transmissão por engrenagens retas**.

A ideia é usar:

- um **pinhão pequeno** no eixo do motor;
- uma **engrenagem maior** no eixo da roda.

Montagem básica:

```text
motor → pinhão pequeno → engrenagem maior → eixo da roda → roda
```

Esse método foi escolhido porque permite aumentar o torque, reduzir a velocidade e testar o chassi com um eixo de roda separado.

---

## 5. Como funciona

O motor gira o próprio eixo. O pinhão preso nesse eixo gira junto e movimenta a engrenagem maior. A engrenagem maior fica presa ao eixo da roda, fazendo a roda girar.

Etapas:

1. O motor gira.
2. O pinhão gira junto com o motor.
3. O pinhão move a engrenagem maior.
4. A engrenagem maior gira o eixo da roda.
5. O eixo gira a roda.

---

## 6. O que prever no CAD

O CAD precisa prever:

- posição dos dois motores;
- suporte firme para os motores;
- espaço para o pinhão;
- espaço para a engrenagem maior;
- furo ou suporte para o eixo da roda;
- bucha ou rolamento para o eixo;
- mesma distância e alinhamento nos dois lados do robô.

Como serão dois motores, a montagem deve ser simétrica:

```text
lado esquerdo: motor + pinhão + engrenagem + eixo + roda
lado direito: motor + pinhão + engrenagem + eixo + roda
```

---

## 7. Cálculos essenciais

### Relação de transmissão

```text
relação = dentes da engrenagem maior ÷ dentes do pinhão
```

Exemplo:

```text
pinhão = 10 dentes
engrenagem maior = 40 dentes

relação = 40 ÷ 10 = 4:1
```

Isso significa que o motor gira 4 voltas para a roda girar 1 volta. A roda fica mais lenta, mas com mais torque.

### RPM da roda

```text
RPM da roda = RPM do motor ÷ relação
```

Exemplo com motor de 750 RPM e relação 4:1:

```text
RPM da roda = 750 ÷ 4 = 187,5 RPM
```

---

## 8. Testes, riscos e conclusão

Antes de usar no robô completo, é necessário testar:

- se a roda gira sem travar;
- se o pinhão e a engrenagem estão alinhados;
- se não existe folga excessiva;
- se os dois lados giram de forma parecida;
- se o robô anda reto.

| Risco | Como evitar |
|---|---|
| Engrenagem travando | Ajustar distância entre motor e eixo da roda |
| Folga | Aproximar as engrenagens sem apertar demais |
| Robô andando torto | Usar peças e relações iguais nos dois lados |
| Atrito no eixo | Usar bucha ou rolamento |
| Motor desalinhando | Prender o motor com suporte firme |

---

## Referências rápidas

## Referências

CANADA ROBOTIX. N20 Micro Metal Gear Motor with Encoder. Disponível em: <https://www.canadarobotix.com/products/2846>. Acesso em: 2 maio 2026.

ROBOTSHOP. Aslong Motor DC 6V 750RPM 3mm Shaft Mini Metal Gearwheel Gear Motor N20 with Encoder Cable. Disponível em: <https://www.robotshop.com/products/aslong-motor-dc-6v-750rpm-3mm-shaft-mini-metal-gearwheel-gear-motor-n20-w-encoder-cable>. Acesso em: 2 maio 2026.

ROBOCORE. Micro Motor com Caixa de Redução 6V 750RPM com Encoder. Disponível em: <https://www.robocore.net/motor-motoredutor/micro-motor-caixa-de-reducao-6v-750rpm-com-encoder>. Acesso em: 2 maio 2026.

KHK GEARS. Gear technical reference: center distance. Disponível em: <https://khkgears.net/new/gear_knowledge/gear-nomenclature/center-distance.html>. Acesso em: 2 maio 2026.

SDP/SI. Timing belt and pulley technical information. Disponível em: <https://www.sdp-si.com/resources/elements-of-metric-gear-technology/index.php>. Acesso em: 2 maio 2026.

NSK. Bearing technical information. Disponível em: <https://www.nsk.com/products/bearings/>. Acesso em: 2 maio 2026.

UKMARS. UKMARSBot motor selection. Disponível em: <https://ukmars.org/projects/ukmarsbot/ukmarsbot-build-guide/motor-selection/>. Acesso em: 2 maio 2026.

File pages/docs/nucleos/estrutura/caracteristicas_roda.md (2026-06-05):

# Características da Roda e Pneu do Micromouse

## 1. Introdução

Nesse documento, estão descritas as características centrais e demais informações referentes ao modelo de roda (que inclui a roda interna e o pneu) selecionado para o projeto de micromouse, que possuirá duas rodas na parte de trás da carcaça e um deslizador (skid) na frente.

As características definidas foram baseadas em diversos fatores, os quais estão, em sua maioria, descritos na página [*Esboço de características desejáveis das rodas*](pages/docs/nucleos/estrutura/esboco_caracteristicas_desejaveis_rodas.md). Além disso, a escolha também foi influenciada pelo fato de integrantes da equipe se disporem a emprestar rodas que possuiam, com propriedades adequadas, para o projeto. Essa abordagem permite que o grupo corte o custo de compra das rodas, e dispensa o tempo necessário para a encomenda e entrega do produto.

Em uma abordagem inicial, seria utilizado o conjunto roda interna ABS + pneu originais (Modelo 1.0 da roda). Em decisão posterior (Modelo 1.1), visando o encaixe com o eixo do motor, foi decidida que seria utilizado apenas o pneu emprestado, enquanto a roda interna seria impressa conforme CAD realizado.

<br>

## 2. Propriedades

### 2.1. Material

O pneu é composto de um **elastômero termoplástico (TPE)** chamado de **SBS** (*estireno-butadieno-estireno*). Esse material é conhecido pela sua flexibilidade, maciez e alta aderência, sendo essa última fundamental para o desejável alto atrito com o solo.

A roda interna, moldada e impressa para o encaixe com o pneu, é feita de filamento ASA (*Acrilonitrila Estireno Acrilato*), um plástico de alta resistência térmica comumente utilizado em impressões 3D.

### 2.2. Dimensões

O pneu possui um diâmetro de *30 mm* e largura de *11 mm*. A roda interna, por sua vez, possui diâmetro de *17,75 mm* e largura de *7 mm*, além de um vão em formato de "D" no seu eixo de 
diamêtro *3,06 mm* e distância até a linha *2,6 mm*.

### 2.3. Textura da banda de rodagem

A textura da banda de rodagem é composta por uma linha central lisa com largura *1,94 mm*, e sulcos de comprimento *2,75 mm* em ambos os lados por toda a superfície.

Apesar de ser preferível uma superfície sem sulcos, para maximizar o atrito com a superfície lisa em *MDF*, a existência de sulcos não trará impactos negativos significantes para essa questão, dado o escopo e o contexto do projeto.

<br>

## 3. Desenhos Técnicos

Abaixo, estão apresentados os desenhos técnicos da roda interna e do pneu.

<p align="center"><i>Imagem 1:</i> Desenho técnico da Roda Interna</p>

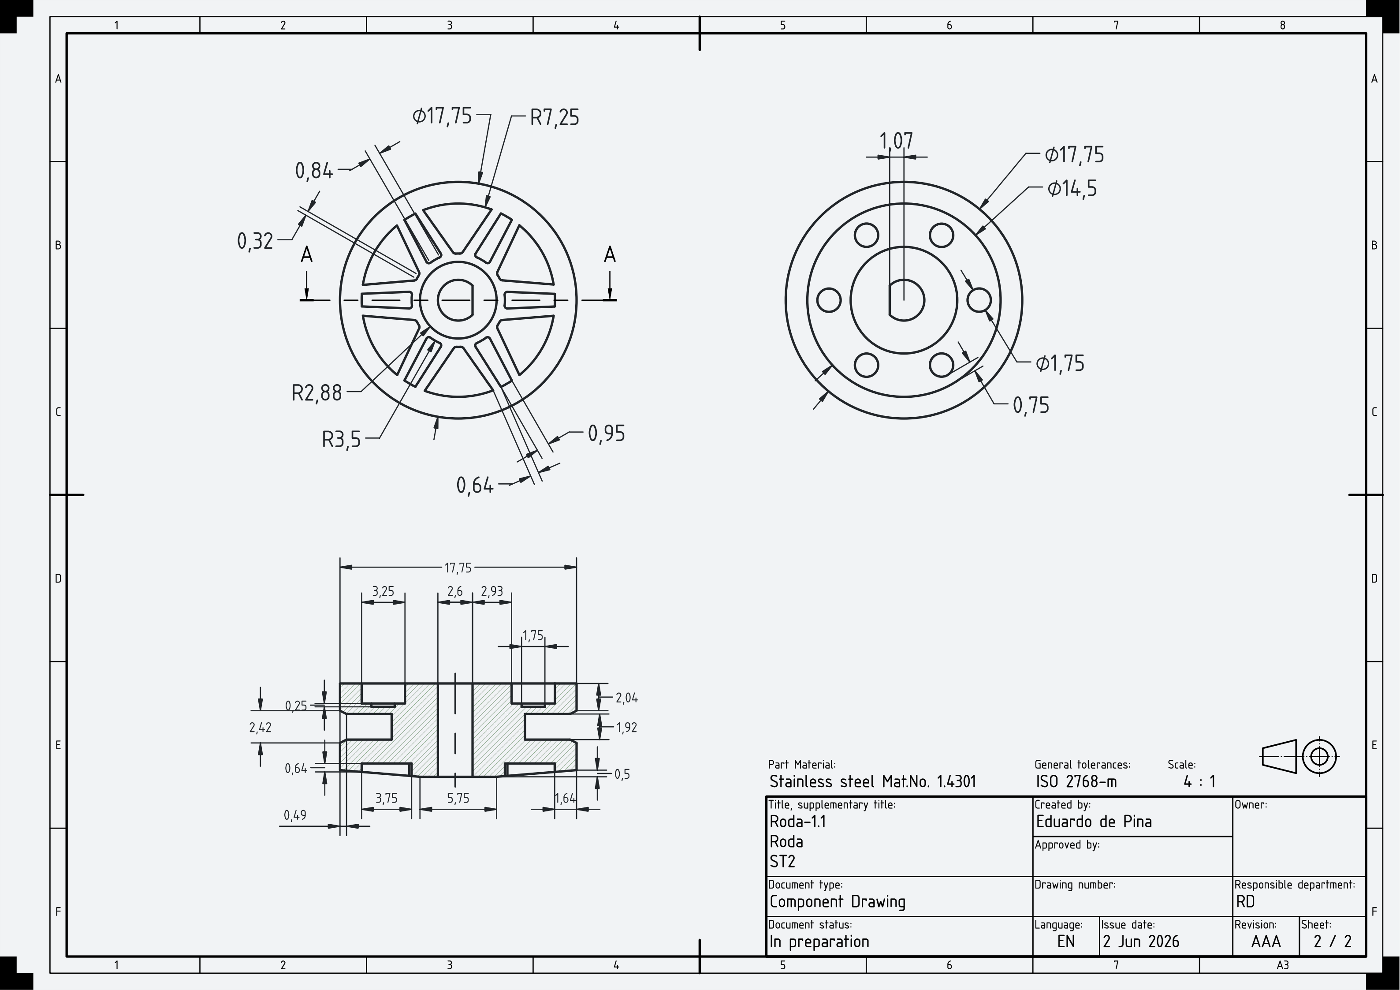
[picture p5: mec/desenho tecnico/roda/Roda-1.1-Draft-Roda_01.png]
Roda Interna


<p align="center"><b>Fonte: </b>Autoria de <a href="https://github.com/eduardodpms">Eduardo de Pina</a></p>

<br>

<p align="center"><i>Imagem 2:</i> Desenho técnico do Pneu</p>

Pneu

<p align="center"><b>Fonte: </b>Autoria de <a href="https://github.com/eduardodpms">Eduardo de Pina</a></p>

<br>

## 4. Tabela de Versionamento

| Versão | Data | Autor | Descrição | Revisor |
| :-: | :-: | :-: | :-: | :-: |
| 1.0 | 12/05/2026 | [Eduardo de Pina](https://github.com/eduardodpms) | Criação do documento | [Giovanni Mateus](https://github.com/GiovanniMateus) |
| 1.1 | 02/06/2026 | [Eduardo de Pina](https://github.com/eduardodpms) | Adição de informações do ajuste da roda | [Giovanni Mateus](https://github.com/GiovanniMateus) |

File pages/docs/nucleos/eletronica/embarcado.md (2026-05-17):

## Backlog do Produto

O *Backlog* do Produto consolida as necessidades e funcionalidades do sistema Micromouse, sendo estruturado para garantir a rastreabilidade e a priorização adequada das entregas. As funcionalidades do sistema foram documentadas diretamente utilizando-se a técnica de Histórias de Usuário (HU), permitindo a compreensão clara das necessidades dos atores sob a perspectiva de valor de negócio.

Para a priorização dos itens, adotou-se o método MoSCoW, classificando as funcionalidades em *Must Have* (essenciais), *Should Have* (importantes, mas não vitais) e *Could Have* (desejáveis). Adicionalmente, os requisitos não-funcionais (RNF) foram definidos sob critérios objetivos, evitando descrições subjetivas e focando em métricas mensuráveis de desempenho, como tempo de resposta e estabilidade da conexão.

Todas as Histórias de Usuário (HUs) possuem descrição estruturada no formato **Eu–Como–Para**, critérios de aceitação e protótipos de interface devidamente documentados. A estrutura completa do Backlog do Produto encontra-se disponível no [Backlog do Projeto no GitHub](https://github.com/orgs/fcte-pi1/projects/16/views/1), permitindo rastreabilidade e acompanhamento detalhado do desenvolvimento do projeto.

Vale ressaltar que este documento foca nos épicos e requisitos relacionados ao desenvolvimento de sistemas **Embarcados**. A parte complementar do backlog, com foco no sistema web e gerenciamento de dados, pode ser encontrada na seção de [Software](../software/backlog-produto.md).

As tabelas a seguir apresentam a divisão do backlog organizada por épicos de desenvolvimento.

---

### Épico A: Desenvolvimento de Firmware

| ID | Título da História | Priorização (MoSCoW) | História de Usuário | Critério de Aceite |
| :---- | :---- | ----- | :---- | :---- |
| **HU-02** | Percepção e Segurança | Must Have | Eu como avaliador, desejo que o circuito tenha sensores de distância e proteções elétricas, para que o robô detecte paredes sem sofrer danos. | **CA-02-01**:Sensores IR devem detectar objetos a pelo menos 30 cm. **CA-02-02**:PCB com proteção contra curto-circuitos para prevenir danos ao MCU. **CA-02-03**:Sistema de sensores deve cobrir angulação de pelo menos 90°. |
| **HU-03** | Controle e Energia | Must Have | Eu como sistema embarcado, quero processar os sinais dos encoders e sensores inerciais, para que o Micromouse execute movimentos precisos. | **CA-03-01:** O sistema deve converter os pulsos dos encoders em velocidade linear e angular do robô **CA-03-02:** O sistema deve atualizar continuamente a posição estimada do robô com base na odometria **CA-03-03:** O sistema deve utilizar dados do acelerômetro para detectar impactos ou desvios de trajetória **CA-03-04:** O sistema deve ajustar o controle de movimento para manter a trajetória desejada durante a navegação |
| **HU-04** | Persistência de Dados | Should Have | Eu como desenvolvedor, quero que o robô armazene a telemetria em um cartão SD, para garantir que os dados não sejam perdidos. | **CA-04-01**:Gravar dados em tempo real no SD Card em formato CSV ou JSON. **CA-04-02**:Garantir a integridade do arquivo mesmo se a alimentação for interrompida bruscamente |
| **HU-06** | Energização e Bateria | Must Have | Eu como avaliador, quero que o sistema de energia permita recarregar a bateria e forneça alimentação estável. | **CA-06-01**: O sistema deve iniciar a recarga automaticamente ao ser conectado a uma fonte de energia externa compatível. **CA-06-02:** A conexão física deve ser robusta o suficiente para suportar múltiplos ciclos de conexão/desconexão sem perda de contato. **CA-06-03**: O sistema deve fornecer tensões constantes (ex: 3.3V, 5V, 12V) independentemente da queda gradual de tensão da bateria principal (enquanto houver carga). |
| **HU-07** | Unificação do Sistema | Must Have | Eu como avaliador, desejo que todos os subsistemas estejam integrados em uma única plataforma funcional. | **CA-07-01**: O firmware principal deve ser capaz de gerenciar simultaneamente a leitura dos sensores e o controle dos motores sem travamentos. **CA-07-02**: Os dados de telemetria coletados devem refletir com precisão o estado real de todos os sensores integrados. **CA-07-03**: A integração física de todos os componentes na PCB não deve apresentar interferências eletromagnéticas que comprometam o funcionamento do sistema. |

### Épico E: Envio de Dados de Telemetria

| ID | Título da História | Priorização (MoSCoW) | História de Usuário | Critério de Aceite |
| :---- | :---- | ----- | :---- | :---- |
| **HU-20** | Comunicação Micromouse | Must Have | Eu como avaliador quero que o sistema web se comunique com o micromouse para obter dados. | **CA-20-01: Dado** que o micromouse e o sistema estão ligados. Quando a comunicação for iniciada; Então o sistema web e o micromouse devem estabelecer uma sessão de conexão. |
| **HU-22** | Aglutinação de Dados | Must Have | Eu como avaliador, quero que o sistema organize e formate os dados de telemetria em pacotes estruturados para envio sem fio. | **CA-22-01**: O sistema deve agrupar as leituras dos sensores IR, encoders e IMU em uma única estrutura de dados (struct) ou string formatada. **CA-22-02:** A formatação dos dados deve ser compatível com a transmissão via protocolos sem fio suportados pelo ESP-32 (como UDP/TCP via WiFi ou Serial Bluetooth). |

### Épico F: Corrida para a Chegada

| ID | Título da História | Priorização (MoSCoW) | História de Usuário | Critério de Aceite |
| :---- | :---- | ----- | :---- | :---- |
| **HU-05** | Calibração de Sensores | Must Have | Eu Como avaliador, desejo que o robô realize uma calibração automática de seus sensores de luminosidade antes do início da prova, para que as variações de luz do ambiente não interfiram na precisão da leitura durante a navegação. | **CA-05-01**:Executar calibração automática de luz ambiente antes da largada. **CA-05-02**:Recalcular posição com erro máximo de \+/- 1 cm após derrapagem. |
| **HU-23** | Aglutinação de Dados em formato Enviável | Must Have | Eu Como avaliador, desejo que o robô identifique e corrija desvios de posição causados por colisões ou derrapagens, para que o mapeamento não seja corrompido e a navegação continue de forma precisa. | - |

### Histórias de Usuário Adicionais

| ID | Título da História | Priorização (MoSCoW) | História de Usuário | Critério de Aceite |
| :---- | :---- | ----- | :---- | :---- |
| **HU-01** | Exploração Autônoma | Must Have | Eu Como avaliador, desejo que o robô mapeie e resolva o labirinto de forma autônoma, para que ele alcance o objetivo central de forma eficiente. | **CA-01-01**:Utilizar algoritmo *Frontier-based Exploration* para achar a célula final. **CA-01-02**:Detectar e trocar de algoritmo ao alcançar o centro. **CA-01-03**:Utilizar *Flood Fill* para mapear a área. **CA-01-04**:Evitar loops infinitos armazenando células visitadas. |

### **Requisitos Não-Funcionais de Embarcados**

| ID | Descrição do Requisito Não Funcional | Priorização (MOSCOW) | Rastreabilidade |
| :---- | :---- | ----- | :---- |
| **RNF-01-EMB** | O sistema deve possuir sensores capazes de detectar objetos a pelo menos de 30 cm de distância. | Must Have | HU-02 |
| **RNF-02-EMB** | O sistema de sensores deve detectar objetos com angulação de pelo menos 90° com o robô parado. | Must Have | HU-02 |
| **RNF-03-EMB** | O micromouse não deve exceder 10 cm de largura ou comprimento. | Must Have | HU-01 |
| **RNF-04-EMB** | O robô não pode causar danos às paredes ou ao chão do labirinto. | Must Have | HU-02 |
| **RNF-05-EMB** | O algoritmo deve ser capaz de recuperar a posição do robô caso ocorra uma leve colisão ou derrapagem. | Should Have | HU-05 |
| **RNF-06-EMB** | O sistema deve utilizar o algoritmo frontier-based exploration para encontrar a célula final. | Must Have | HU-01 |
| **RNF-07-EMB** | O sistema deve utilizar o algoritmo Flood Fill para mapear toda a área explorável. | Must Have | HU-01 |
| **RNF-08-EMB** | O código deve ser modular para facilitar ajustes rápidos. | Should Have | HU-05/HU-07 |

## Histórico de Versões

|Versão|Data|Autor|Descrição|Revisor |
|---|---|---|---|---|
|1.0|13/05/2026|[Enzo Emir](https://github.com/EnzoEmir)|Criação do documento| -|

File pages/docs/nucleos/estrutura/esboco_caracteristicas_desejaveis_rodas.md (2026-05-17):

# Esboço das características desejáveis das rodas

## 1. Introdução

Seguindo o modelo inicial de CAD para o robô desenvolvida pelo núcleo de estrutura e pesquisas direcionadas, foram discutidas medidas provisórias para serem utilizadas como base na seleção das rodas e pneus que serão utilizados no MicroMouse, buscando cumprir o objetivo da equipe.

<br>

## 2. CAD e Vãos

A base do modelo do robô está apresentada por meio de um CAD neste repositório. A imagem a seguir exibe, em vista tridimensional, uma captura de tela desse modelo.

CAD da Base

Os vãos destinados as rodas têm as dimensões de **30mm** x **14mm**, o que dá um direcionamento para a decisão da faixa de tamanhos possíveis para a roda.

<br>

## 3. Largura dos Pneus

A largura dos pneus, ou largura da banda de rodagem, é um fator que influencia diretamente na estabilidade do robô, assim como na precisão em curvas e no atrito com o solo. De forma resumida, para um *micromouse*, rodas mais finas proporcionam curvas mais precisas, enquanto rodas mais grossas proporcionam maior estabilidade para a estrutura como um todo, e maior área de contato do pneu com o solo, isto é, maior atrito.

Considerando o objetivo central da equipe, que não está focada em desenvolver um robô competitivo, e sim um robô estável, funcional, testável, e capaz de superar pequenos buracos de encaixe no labirinto, haverá uma preferência por rodas mais grossas (banda de rodagem > **1cm**). Além disso, há um espaço de **14mm** disponível para a roda no modelo inicial do chassi, o que não implica em um fator limitante para esse tamanho (já que uma parte do excesso pode extrapolar a largura do robô), mas dá um direcionamento nesse sentido.

Nesse sentido, a faixa ideal de largura da roda, seguindo o alinhamento da equipe, é de `11mm - 15mm`.

<br>

## 4. Diâmetro dos Pneus

O diâmetro dos pneus é outro fator decisivo na relação de escolha da roda. Rodas maiores tendem a fornecer maior velocidade em troca de mais torque, enquanto rodas menores tendem a fornecer mais precisão. Adicionalmente, aqui há um fator limitante para essa escolha: o comprimento do vão do chassi, que deve ser estritamente maior que o pneu para permitir a rolagem.

Para isso, será definida uma faixa de diâmetros de `20mm - 25mm`, que garantirá ao menos **5mm** de folga para a rolagem dos pneus, proporcionando também um tamanho que respeite a estrutura geral do *micromouse*.

<br>

## 5. Grip e Atrito

O *grip* é uma variável complexa que analisa fatores como [material](#6-material), textura e [largura dos pneus](#3-largura-dos-pneus), condições e material da pista para maximizar o atrito na superficie. Esse objetivo é central no desenvolvimento do projeto, uma vez que pneus sem atrito dificultam a previsibilidade e o cálculo dos movimentos do robô, além de também prejudicarem o controle sobre os mesmos.

Em relação às condições da pista, é esperado que a mesma seja construida sobre um material *mdf*, sem quantidades relevantes de umidade ou poeira, o que dispensa a necessidade de *sulcos* na banda de rodagem. Com relação à textura do material do pneu, o ideal seria um pneu liso, para maximizar o *grip* com o solo, mesmo essa abordagem tendendo a proporcionar maior desgaste do pneu com o tempo.

Nesse sentido, apesar de **preferível** que não haja textura na banda de rodagem, e existência de sulcos não impactará significativamente no atrito com o solo a ponto de prejudicar a equipe.

<br>

## 6. Material

Por fim, a respeito do material do pneu, é desejado um material macio e aderente. Para isso, é preferível alguma derivação de **borracha sintética**, como aquelas utilizadas nas peças de *Lego* (*SBS* e *SEBS*). Por fins de personalização, uma alternativa plástica seria o *filamento TPU*, utilizado em impressoras 3D.

<br>

## 7. Referências utilizadas

JAIN, J. **Robot Wheel Traction: Surface & Tire Type Selection Guide**. ZBOTIC. Disponível em: https://zbotic.in/robot-wheel-traction-surface-tire-type-selection-guide. Acesso em 4 maio 2026.

**How to choose proper Tires**. Micromouse USA. Disponível em: http://micromouseusa.com/?p=1111. Acesso em 4 maio 2026.

**What is The Role of Tire Size in Speed, Grip, and Stability?**. Brewminate. Disponível em: https://brewminate.com/what-is-the-role-of-tire-size-in-speed-grip-and-stability. Acesso em 4 maio 2026.

**De que são feitas as peças LEGO®?**. LEGO. Disponível em: https://www.lego.com/pt-br/service/help-topics/article/what-lego-bricks-are-made-of. Acesso em 4 maio 2026.

<br>

## 8. Tabela de Versionamento

| Versão | Data | Autor | Descrição | Revisor |
| :-: | :-: | :-: | :-: | :-: |
| 1.0 | 05/05/2026 | [Eduardo de Pina](https://github.com/eduardodpms) | Criação do documento | [Caio Venâncio](https://github.com/caio-venancio) |

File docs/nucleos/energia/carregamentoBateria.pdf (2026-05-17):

# Sistemas de Carregamento

A escolha entre baterias recarregáveis e descartáveis para o desenvolvimento de um robô que resolve labirintos é um fator importante para a viabilidade técnica do projeto. As recarregáveis de Li-ion 18650 mostram-se superiores por possuírem alta densidade energética, o que permite atingir maior autonomia com eficiência. Diferente das descartáveis, que sofrem quedas graduais de voltagem, as baterias de lítio mantêm uma tensão estável, garantindo que os motores preservem o torque e os sensores operem com precisão constante.

Embora pilhas descartáveis apresentem menor custo inicial, o sistema não suporta os picos de corrente exigidos pela movimentação, o que frequentemente causa reinicializações no microcontrolador.

Para carregar baterias de Li-ion e especificamente as células do formato 18650 existem algumas abordagens principais:

## 1. Carregadores Externos (Slot)

Esta é a opção mais segura e prática para quem utiliza pilhas individuais, como a Pilha GREEN 18650.

- Funcionamento: Remove-se as pilhas do compartimento do robô e as coloca em um carregador de tomada dedicado.
- Vantagens: Possuem circuitos de proteção internos que controlam a corrente e a tensão automaticamente, desligando ao atingir a carga total.

## 2. Módulos de Carga TP4056 (Carga via USB)

É possível carregar as baterias sem removê-las do robô, este módulo é uma boa opção para prototipagem com células 18650 de 3.7V.

- Funcionamento: Um pequeno chip que recebe energia de uma porta Micro-USB ou USB-C e gerencia a carga da bateria.
- Integração: Pode ser colado ou parafusado na estrutura do "rato" robótico.

Comparativo de Usabilidade

Opção | Melhor para... | Facilidade

Carregador de Slot | Pilhas individuais (ex: GREEN 18650) | Alta (Plug & Play)
Módulo TP4056 | Carregamento interno via USB (Praticidade no campo) | Média (Exige solda)

Comparativo de Custo-Benefício e Segurança

Critério | Carregador Externo (Slot) | Módulo TP4056 (Com Proteção)
Custo Inicial | Maior. Um carregador confiável custa entre R$ 40 e R$ 100. | Muito Baixo. Cada módulo custa entre R$ 5 e R$ 10.
Segurança | Alta. Possui circuitos dedicados e carcaça isolante profissional. | Média. Depende da qualidade da soldagem e do isolamento no robô.
Praticidade | Baixa. Exige remover as pilhas do robô toda vez que for carregar. | Alta. Permite carregar via USB (como um celular) sem abrir o robô.
Proteção no Uso | Nenhuma. Ele só protege durante a carga, não enquanto o robô corre. | Completa. Protege contra descarga excessiva e curto-circuito durante a operação.
Escalabilidade | Limitado ao número de slots físicos do aparelho. | Pode ser integrado individualmente para cada pack de bateria.

## 3. Exemplos para Aquisição

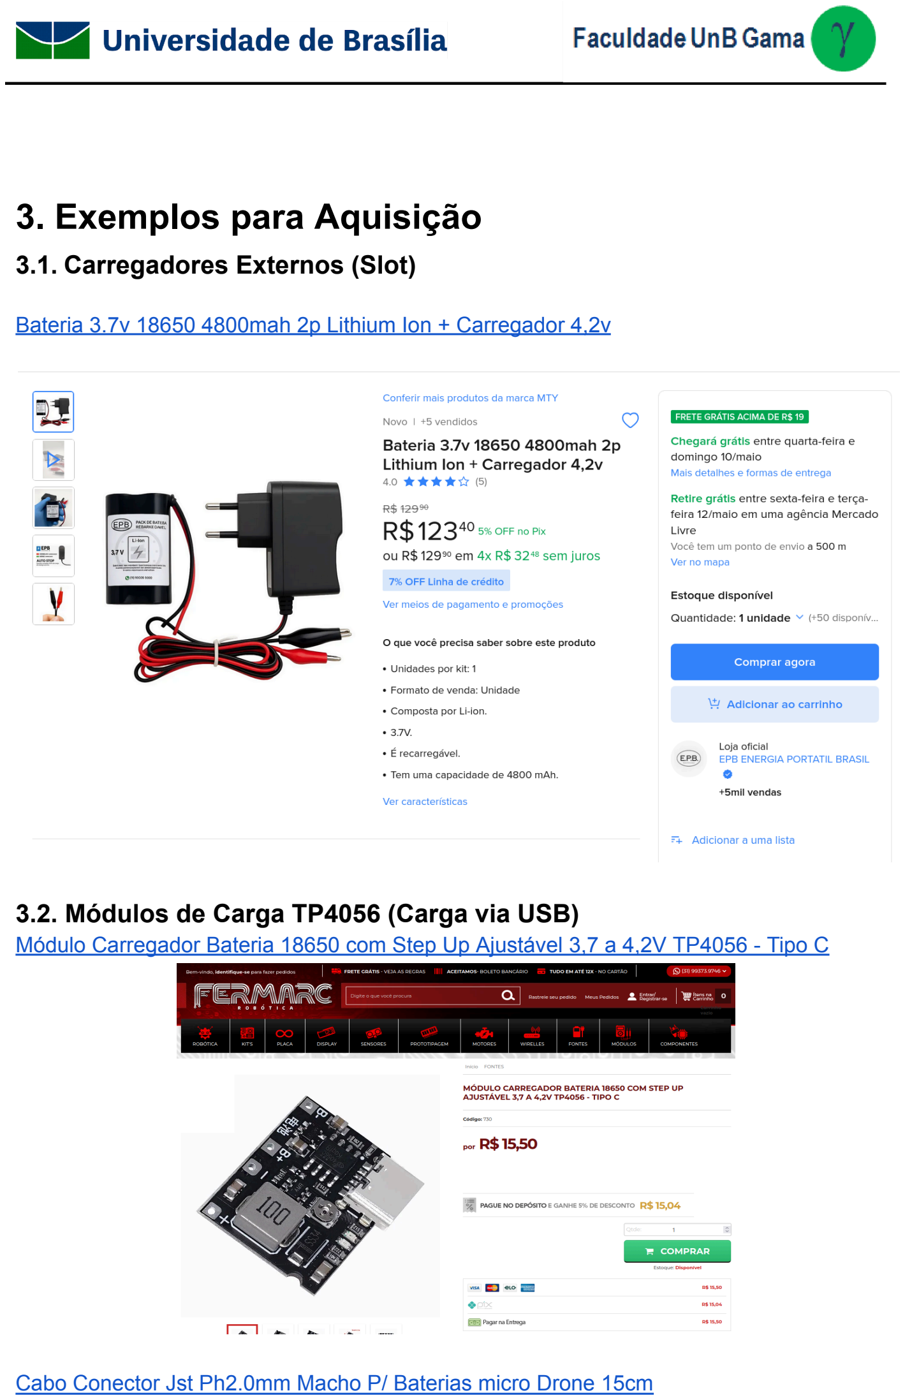
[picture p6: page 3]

### 3.1. Carregadores Externos (Slot)

Bateria 3.7v 18650 4800mah 2p Lithium Ion + Carregador 4,2v (https://www.mercadolivre.com.br/bateria-37v-18650-4800mah-2p-lithium-ion---carregador-42v/up/MLBU1404615007)

### 3.2. Módulos de Carga TP4056 (Carga via USB)

Módulo Carregador Bateria 18650 com Step Up Ajustável 3,7 a 4,2V TP4056 - Tipo C (https://www.fermarc.com/m-dulo-carregador-bateria-18650-com-step-up-ajust-vel-3-7-a-4-2v-tp4056)

Cabo Conector Jst Ph2.0mm Macho P/ Baterias micro Drone 15cm (https://shopee.com.br/product/313771325/22897898149?gad_source=1&gad_campaignid=21445281076)

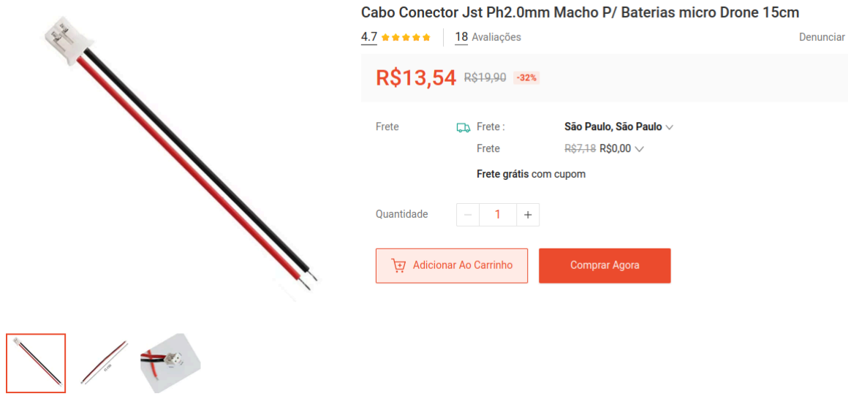
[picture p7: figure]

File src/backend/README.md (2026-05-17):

# Micromouse Backend

Este é o servidor backend para o projeto Micromouse, desenvolvido com FastAPI e PostgreSQL.

## 🚀 Tecnologias
- [Python 3.12+](https://www.python.org/)
- [FastAPI](https://fastapi.tiangolo.com/)
- [SQLModel](https://sqlmodel.tiangolo.com/) (SQLAlchemy + Pydantic)
- [PostgreSQL](https://www.postgresql.org/)
- [Docker](https://www.docker.com/) & [Docker Compose](https://docs.docker.com/compose/)

## 🛠️ Como rodar o projeto

### 1. Pré-requisitos
Certifique-se de ter instalado:
- Python 3.12 ou superior
- Docker e Docker Compose

### 2. Configuração do Ambiente
Navegue até a pasta do backend:
```bash
cd src/backend
```

Crie um arquivo `.env` baseado no exemplo:
```bash
cp .env.example .env
```
*(O arquivo `.env.example` já vem configurado para conectar ao banco de dados local via Docker)*.

### 3. Usando Docker (Recomendado)
Para rodar a aplicação completa (API + Banco de Dados) via Docker:

```bash
docker compose up -d --build
```
Isso iniciará o banco de dados PostgreSQL e a API FastAPI.
O servidor estará disponível em: [http://localhost:8000](http://localhost:8000)

### 4. Rodando Localmente (Desenvolvimento)
Caso prefira rodar apenas o banco no Docker e a API localmente:

Inicie apenas o banco de dados:
```bash
docker compose up db -d
```

Crie e ative um ambiente virtual:
```bash
python -m venv .venv
source .venv/bin/activate  # Linux/macOS
# ou
.venv\Scripts\activate     # Windows
```

Instale as dependências:
```bash
pip install -r requirements.txt
```

Inicie o servidor de desenvolvimento:
```bash
fastapi dev app/main.py
```

O servidor estará disponível em: [http://localhost:8000](http://localhost:8000)

## 🔄 Migrações (Alembic)

O projeto utiliza o **Alembic** para gerenciar as migrações do banco de dados. Certifique-se de estar com o ambiente virtual ativado e na pasta `src/backend`.

### Aplicar Migrações
Para aplicar as migrações existentes ao banco de dados (atualizar o banco):
```bash
alembic upgrade head
```

### Criar uma Nova Migração
Se você fizer alterações nos modelos em `app/models/`, gere uma nova migração com:
```bash
alembic revision --autogenerate -m "Descrição da migração"
```

### Verificar o Estado Atual
Para ver qual a migração atual aplicada no banco:
```bash
alembic current
```

## 📖 Documentação (Swagger)
Após iniciar o servidor, você pode acessar a documentação interativa da API:
- **Swagger UI**: [http://localhost:8000/docs](http://localhost:8000/docs)
- **Redoc**: [http://localhost:8000/redoc](http://localhost:8000/redoc)

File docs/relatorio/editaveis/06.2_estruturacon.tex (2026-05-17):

Nesta seção, são apresentadas as decisões técnicas relacionadas à estrutura mecânica do robô micromouse, incluindo os materiais utilizados, o dimesionamento e os desenhos técnicos desenvolvidos para o projeto.

%Talvez uma foto do carrinho montado aqui

\subsection{Escolha dos materiais}

%Talvez matriz de decisão para escolha de materiais

introducao

\subsubsection{Cálculo térmico}

Metodologia de cálculo térmico

Critério de falha térmica

Tabela de falha térmica

\subsubsection{Análise do coeficiente de atrito}

Tabela de coeficiente de atrito

\subsection{Dimensionamento estrutural}

\subsubsection{Base do Chassi}

\subsubsection{Chassi superior}

\subsubsection{Rodas}

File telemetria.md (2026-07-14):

# Especificação de Telemetria Minimalista (ESP32 -> Web)

---

O campo `tipo` está sempre presente como **primeiro campo** de todos os pacotes, permitindo que o web identifique o tipo sem precisar inspecionar o conteúdo restante.

| `tipo` | Pacote |
|---|---|
| `0` | Configuração Inicial |
| `1` | Movimentação / Descoberta de Paredes |
| `2` | Rota Otimizada |
| `3` | Fim de Corrida |
| `4` | Heartbeat |
| `5` | Alerta Crítico de Temperatura |

---

## 1. Configuração Inicial (Disparado uma única vez na largada)
Envia o tamanho do labirinto e o número da tentativa para preparar a interface web.

```json
{
  "tipo": 0,
  "timestamp_ms": 0,
  "dimensao": 4,
  "lado_largada": "esquerda",
  "bateria": 100
}
```

- tipo (int): Identificador do tipo de pacote (0 = Configuração Inicial).
- timestamp_ms (int): Timestamp relativo ao inicio da corrida, em milissegundos.
- dimensao (int): Tamanho do labirinto atual. Enviar 4 para 4x4, 8 para 8x8 ou 16 para 16x16.
- lado_largada (string): Lado em que o mapeamento começa, `"esquerda"` (canto oeste, x=0) ou `"direita"` (canto leste, x=n-1). A frente do robô na largada é sempre o Norte do modelo.
- bateria (int): Porcentagem estimada restante da bateria no inicio do teste (de 0 a 100).

## Convenção Espacial e de Coordenadas 

Para alinhar perfeitamente a lógica matemática do firmware em C++ com a renderização visual, adotamos o **Sistema Cartesiano Padrão**:

* **Origem `[0,0]`:** Localizada no **canto inferior esquerdo** do labirinto.
* **Eixo X:** Cresce para a **direita** (Direção Leste).
* **Eixo Y:** Cresce para **cima** (Direção Norte).

### Impacto na Movimentação do Robô (Lógica do ESP32):
* **Andar para o Norte:** Avança para frente $\rightarrow$ **Soma 1 em Y** (`y++`)
* **Andar para o Sul:** Anda para trás $\rightarrow$ **Subtrai 1 em Y** (`y--`)
* **Andar para o Leste:** Vira/anda para a direita $\rightarrow$ **Soma 1 em X** (`x++`)
* **Andar para o Oeste:** Vira/anda para a esquerda $\rightarrow$ **Subtrai 1 em X** (`x--`)

## 2. Movimentação e Descoberta de Paredes (Disparado APENAS ao mudar de célula)

Em vez de enviar dados por tempo (streaming contínuo), o ESP32 enviará este pacote pequeno somente quando o robô efetivamente entrar em uma nova célula durante a exploração (Frontier-Based).

```json
{
  "tipo": 1,
  "timestamp_ms": 1234,
  "x": 2,
  "y": 1,
  "w": 5
}
```

- tipo (int): Identificador do tipo de pacote (1 = Movimentação / Descoberta de Paredes).
- timestamp_ms (int): Timestamp relativo ao inicio da corrida, em milissegundos.
- x (int): Coordenada X atual do robô no labirinto, seguindo a convenção definida acima.
- y (int): Coordenada Y atual do robô no labirinto, seguindo a convenção definida acima.
- w (int): Bitmask (máscara de bits) das paredes descobertas nesta célula específica.

Convenção do Bitmask de Paredes (w):

A equipe web deve ler o valor inteiro e decodificar os bits para desenhar as paredes no site:

- Norte = bit 0 (Peso 1)
- Sul = bit 1 (Peso 2)
- Leste = bit 2 (Peso 4)
- Oeste = bit 3 (Peso 8)

    Exemplo: Se o JSON enviar "w": 5 (1 + 4), significa que a célula atual possui paredes ao Norte e ao Leste.

## 3. Rota Otimizada (Disparado uma única vez após o cálculo do Floodfill)

Envia a lista sequencial de coordenadas que formam o caminho perfeito calculado pelo algoritmo antes de iniciar a corrida rápida (Fast Run).

```json
{
  "tipo": 2,
  "timestamp_ms": 9000,
  "rota": [[0,0], [0,1], [0,2], [1,2], [2,2]]
}
```

- tipo (int): Identificador do tipo de pacote (2 = Rota Otimizada).
- timestamp_ms (int): Timestamp relativo ao inicio da corrida, em milissegundos.
- rota (array de arrays): Coordenadas consecutivas [x, y] do início ao fim do trajeto ideal. O site usará isso para desenhar a linha do caminho ótimo na tela.

## 4. Fim de Corrida / Consolidação (Disparado uma única vez ao terminar/falhar)

Contém os dados consolidados exigidos pelos professores. Este pacote fecha a rodada e deve ser salvo de forma permanente no banco de dados.

```json
{
  "tipo": 3,
  "timestamp_ms": 14250,
  "sucesso": true,
  "v_med": 0.22,
  "bateria": 88
}
```

- tipo (int): Identificador do tipo de pacote (3 = Fim de Corrida).
- timestamp_ms (int): Timestamp relativo ao inicio da corrida, em milissegundos.
- sucesso (boolean): true se o robô alcançou o centro autonomamente ou false se colidiu/desistiu.
- v_med (float): Velocidade média final do percurso em metros por segundo.
- bateria (int): Porcentagem estimada restante da bateria no final do teste (de 0 a 100).

***
## 5. Heartbeat (Disparado periodicamente enquanto o ESP32 estiver ativo)

Enviado em intervalos regulares (a cada 1,5 segundos) para indicar que a conexão com o ESP32 está viva. Se o web não receber este pacote dentro do intervalo esperado, deve exibir um aviso de conexão perdida.

```json
{
  "tipo": 4,
  "timestamp_ms": 5000,
  "bateria": 95
}
```

- tipo (int): Identificador do tipo de pacote (4 = Heartbeat).
- timestamp_ms (int): Timestamp relativo ao inicio da corrida, em milissegundos.
- bateria (int): Porcentagem estimada restante da bateria no momento do envio (de 0 a 100). Permite monitorar o consumo ao longo da corrida.

> **Comportamento esperado no Web:** Se nenhum pacote de qualquer tipo (incluindo heartbeat) for recebido por mais de **3 segundos**, a interface deve exibir indicador visual de "Conexão Perdida".

---

## 6. Alerta Crítico de Temperatura (Disparado quando a temperatura ultrapassa o limiar seguro)

Enviado imediatamente sempre que o sensor de temperatura detectar valor acima do limiar crítico configurado no firmware. A corrida é interrompida automaticamente após este pacote. O web deve exibir um alerta visual de emergência.

```json
{
  "tipo": 5,
  "timestamp_ms": 7800,
  "temp_c": 61.0,
}
```

- tipo (int): Identificador do tipo de pacote (5 = Alerta Crítico de Temperatura).
- timestamp_ms (int): Timestamp relativo ao inicio da corrida, em milissegundos.
- temp_c (float): Temperatura atual medida pelo sensor, em graus Celsius.

***

### Alinhamento com os Requisitos de Avaliação da Disciplina:
* **Labirintos:** O campo `dimensao` mapeia se o teste ocorre no labirinto $4\times4$, $8\times8$ ou $16\times16$.
* **Trajeto:** As coordenadas `x`, `y` enviadas por célula preenchem dinamicamente o trajeto em tempo real e a `rota` exibe a inteligência do Floodfill.
* **Persistência e Relatórios:** Os dados do pacote de **Fim de Corrida** fornecem exatamente o consumo de bateria, velocidade média, tempo de conclusão e status de sucesso que a equipe web precisa gravar no banco de dados para cumprir as exigências de avaliação do projeto.

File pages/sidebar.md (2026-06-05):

- [**Home**](pages/docs/README.md)
- [**Cronograma Geral**](pages/docs/cronograma.md)
- [**EAP Geral**](pages/docs/eap_geral.md)
- [**Gerenciamento de Riscos**](pages/docs/gerenciamento_riscos.md)
- **Núcleos**
  - *1. Eletrônica*
    - [PCB](pages/docs/nucleos/eletronica/pcb.md)
    - [Backlog do Produto](pages/docs/nucleos/eletronica/embarcado.md)
  - [*2. Energia*](pages/docs/nucleos/energia.md)
  - *3. Estrutura*
    - [Atributos de Componentes Eletrônicos](pages/docs/nucleos/estrutura/lista_atributos_componentes.md)
    - Rodas
      - [Características da Roda](pages/docs/nucleos/estrutura/caracteristicas_roda.md)
      - [Esboço de Características Desejáveis](pages/docs/nucleos/estrutura/esboco_caracteristicas_desejaveis_rodas.md)
  - *4. Software*
    - [Arquitetura de Software](pages/docs/nucleos/software/arquitetura-software.md)
    - [Backlog do Produto](pages/docs/nucleos/software/backlog-produto.md)
    - [Roteiro de Testes Funcionais](pages/docs/nucleos/software/roteiro-testes-funcionais.md)
    - [Testes de Software (7.5)](pages/docs/nucleos/software/testes-software.md)

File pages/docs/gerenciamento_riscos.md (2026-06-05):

# Gerenciamento de Riscos

## 1. Introdução

Este documento apresenta o levantamento e o gerenciamento dos principais riscos identificados no desenvolvimento do projeto do Micromouse na disciplina de Projeto Integrador de Engenharia, na UnB/FCTE (2026.1), pelo Grupo 02, orientado pelo docente Hilmer Rodrigues Neri. O trabalho envolve a construção de um robô capaz de resolver labirintos, seguindo uma abordagem scrum.

Por possuir restrições fortes de espaço, integração entre subsistemas e prazo de entrega, a gestão de riscos se torna parte central do planejamento. Assim, o objetivo deste documento é registrar os pontos críticos percebidos pela equipe e propor formas práticas de mitigação, de modo a reduzir impactos sobre prazo, qualidade, integração e funcionamento final do micromouse.

## 2. Metodologia

A identificação dos riscos atual (sprint 8) foi realizada a partir das discussões internas da equipe, feitas em grupo por WhatsApp e complementadas pela reunião de sprint planning. A partir dessas conversas, foram consolidados os principais pontos de atenção de cada núcleo, considerando as decisões já tomadas para o projeto, que direcionaram a medição e estimativa dos dados apresentados aqui.

A análise foi conduzida de forma qualitativa, observando probabilidade de ocorrência, impacto sobre o projeto e relação de dependência entre os núcleos, definindo uma descrição do problema e uma estratégia de mitigação compatível com a equipe e com o estágio atual do desenvolvimento. Também foi conduzida uma análise quantitativa, que utilizou três métricas (Probabilidade, Impacto e Score) para avaliar os riscos selecionados em cada núcleo. Essas métricas, apresentadas abaixo, foram definidas com base nas discussões do grupo e em modelos de gerenciamento de riscos de repositórios da organização [fga-eps-mds](https://github.com/fga-eps-mds) no *GitHub*, conforme orientação docente.

### 2.1 Probabilidade (P)

Possibilidade de o evento ocorrer, ou de a situação trazer um impacto negativo para o desenvolvimento.

| 1 | 2 | 3 | 4 | 5 |
| :---: | :---: | :---: | :---: | :---: |
| **Muito baixo** | **Baixo** | **Regular** | **Alto** | **Muito alto** |

### 2.2 Impacto (I)

O quão relevante será o impacto daquele evento, se ocorrer, para o desenvolvimento do projeto.

| 1 | 2 | 3 | 4 | 5 |
| :---: | :---: | :---: | :---: | :---: |
| **Muito baixo** | **Baixo** | **Regular** | **Alto** | **Muito alto** |

### 2.3 Score (S)

É o produto das duas métricas anteriores (Probabilidade X Impacto). Define o nível de atenção que a equipe deve ter na mitigação/prevenção daquele risco, e a ação para isso.

| Faixa | Classificação do risco | Ação esperada |
| :---: | :---: | :---: |
| 1 - 6 | Baixo | Monitorar |
| 7 - 15 | Médio | Mitigação em pequena escala |
| 16 - 25 | Alto | Ação de mitigação imediata |

## 3. Riscos Identificados

A tabela a seguir resume os riscos identificados pela equipe, junto com o levantamento de métricas (*"Probabilidade" (P)*, *"Impacto" (I)* e *"Score" (S)*), ordenada por *S*.

<p align="center"><i>Tabela 1: Riscos identificados e Score</i></p>

| ID | Riscos Identificados | Área | P | I | S |
| :-: | :- | :-: | :-: | :-: | :-: |
| [1.10](#_5110-risco-de-perda-de-dados-de-telemetria) | Risco de perda de dados de telemetria | `Software` | 4 | 5 | 20 |
| [1.01](#_5101-acúmulo-de-atividades-entre-sprints) | Acúmulo de atividades entre sprints | `Software` | 4 | 4 | 16 |
| [1.02](#_5102-sobrecarga-de-outras-disciplinas) | Sobrecarga de outras disciplinas | `Software` | 4 | 4 | 16 |
| [1.04](#_5104-peso-da-ed2-na-frente-de-software) | Peso da ED2 na frente de software | `Software` | 4 | 4 | 16 |
| [1.07](#_5107-dependência-da-integração-com-a-eletrônica) | Dependência da integração com a eletrônica | `Software` | 4 | 4 | 16 |
| [2.5](#_525-uso-da-impressora-3d) | Uso da Impressora 3D | `Estrutura` | 4 | 4 | 16 |
| [1.03](#_5103-conflitos-de-cronograma) | Conflitos de cronograma | `Software` | 3 | 5 | 15 |
| [1.05](#_5105-baixa-previsibilidade-na-entrega-de-issues) | Baixa previsão na entrega de issues | `Software` | 3 | 5 | 15 |
| [1.12](#_5112-risco-de-atraso-na-integração-software--hardware) | Risco de atraso na integração software + hardware | `Software` | 3 | 5 | 15 |
| [4.3](#_543-logística-para-fabricação-e-envio-da-pcb) | Logística para fabricação e envio da PCB | `Eletrônica` | 3 | 5 | 15 |
| [1.09](#_5109-risco-na-comunicação-do-micromouse-para-o-sistema-web) | Risco na comunicação do Micromouse para Sistema Web | `Software` | 3 | 4 | 12 |
| [1.13](#_5113-débito-técnico) | Débito técnico | `Software` | 3 | 4 | 12 |
| [2.1](#_521-dimensionamento-do-chassi) | Dimensionamento do chassi | `Estrutura` | 3 | 4 | 12 |
| [2.4](#_524-adequação-do-suporte-para-pcb) | Adequação do suporte para PCB | `Estrutura` | 4 | 3 | 12 |
| [2.6](#_526-tempo-curto-para-ajustes-antes-da-entrega-2) | Tempo curto para ajustes antes da entrega 2 | `Estrutura` | 3 | 4 | 12 |
| [3.2](#_532-soldagem-da-bateria) | Soldagem da bateria | `Energia` | 3 | 4 | 12 |
| [1.15](#_5115-dependência-de-participação-contínua-dos-responsáveis) | Dependência de participação contínua dos responsáveis | `Software` | 3 | 3 | 9 |
| [1.06](#_5106-dependências-técnicas-entre-atividades) | Dependências técnicas entre atividades | `Software` | 2 | 4 | 8 |
| [1.11](#_5111-risco-de-inconsistência-na-persistência) | Risco de inconsistência na persistência | `Software` | 2 | 4 | 8 |
| [3.1](#_531-cálculo-de-parâmetros-da-bateria) | Cálculo de parâmetros da bateria | `Energia` | 2 | 4 | 8 |
| [4.2](#_542-integração-de-telemetria) | Integração de telemetria | `Eletrônica` | 2 | 4 | 8 |
| [4.4](#_544-confiabilidade-física) | Confiabilidade física | `Eletrônica` | 2 | 4 | 8 |
| [1.08](#_5108-incerteza-no-fluxo-operacional-da-corrida) | Incerteza no fluxo operacional da corrida | `Software` | 2 | 3 | 6 |
| [1.14](#_5114-documentação-desalinhada-com-a-implementação) | Documentação desalinhada com a implementação | `Software` | 3 | 2 | 6 |
| [2.3](#_523-adequação-do-suporte-dos-sensores) | Adequação do suporte dos sensores | `Estrutura` | 2 | 3 | 6 |
| [3.3](#_533-adequação-do-suporte-da-bateria) | Adequação do suporte da bateria | `Energia` | 3 | 2 | 6 |
| [4.1](#_541-densidade-de-componentes) | Densidade de componentes | `Eletrônica` | 2 | 3 | 6 |
| [2.2](#_522-acoplamento-das-rodas) | Acoplamento das rodas | `Estrutura` | 2 | 2 | 4 |

<p align="center"><i>Fonte: Elaboração própria pelo grupo.</i></p>

<br>

## 4. Esboço do Plano de Gerenciamento de Riscos

A *Figura 1* apresenta um esboço do Plano de Gerenciamento de Riscos da equipe 2 para as sprints 8 e 9 do período de desenvolvimento do produto, que se localizam anteriormente ao ponto de controle 2 (ED2).

<p align="center"><i>Figura 1: Plano de Gerenciamento de Riscos</i></p>

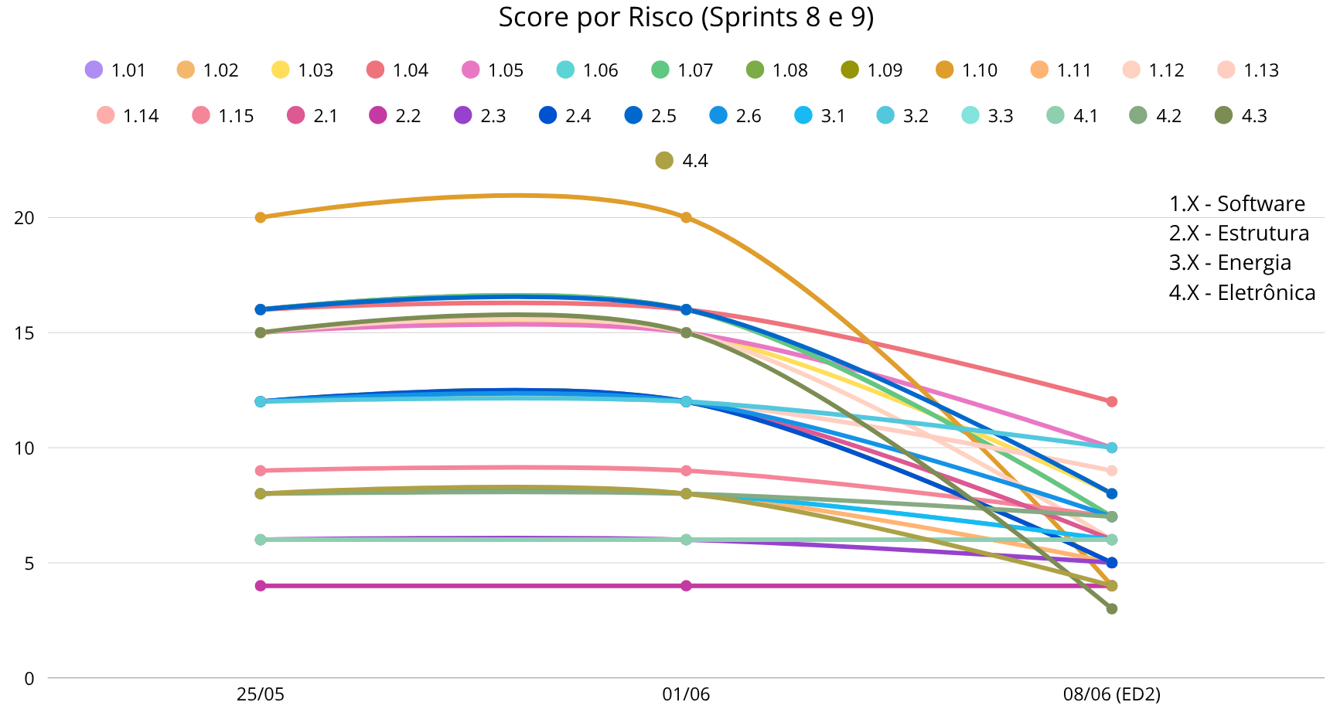
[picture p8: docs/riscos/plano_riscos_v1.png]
Plano de Gerênciamento de Riscos


<p align="center"><i>Fonte: Elaboração própria pelo grupo.</i></p>

O plano de gerenciamento de riscos, elaborado com base nos valores de *Score* calculados pela equipe, apresenta uma queda estimada dos valores dessa métrica após aplicação das ações de mitigação elaboradas pelo time. Essa metodologia apresenta, visualmente, o direcionamento necessário do time para os riscos com maior nível de **Probabilidade X Impacto**, a fim de mitigar os mesmos. Perceba também que os problemas com nível *baixo* e *médio* possuem pouca ou nenhuma variação, uma vez que é esperado que permaneçam “em observação” até que os de alto risco sejam mitigados. Assim, com esse plano de duas sprints, o time possui uma meta de redução das probabilidades e impactos desses riscos que deve ser seguida até a data do segundo ponto de controle.

<br>

## 5. Descrição e Mitigação dos riscos

### 5.1. Núcleo de Software

#### 5.1.01 Acúmulo de atividades entre sprints

**`Descrição:`**
Tarefas pendentes de sprints anteriores estão se acumulando e aumentando a carga da sprint atual.

**`Mitigação:`**
A equipe deve priorizar o fechamento do que já foi iniciado e dividir issues maiores em partes menores, evitando acúmulo silencioso.

#### 5.1.02 Sobrecarga de outras disciplinas

**`Descrição:`**
A baixa disponibilidade dos integrantes, por causa de outras disciplinas, reduz o ritmo e a comunicação da equipe.

**`Mitigação:`**
As tarefas devem ser bem distribuídas e com pouca dependência entre pessoas, para que o andamento não fique concentrado em poucos membros.

#### 5.1.03 Conflitos de cronograma

**`Descrição:`**
Choques entre aulas, avaliações e outras demandas dificultam o cumprimento dos prazos planejados.

**`Mitigação:`**
O cronograma deve ter margem de segurança e ser revisado com frequência para permitir redistribuição rápida das atividades.

#### 5.1.04 Peso da ED2 na frente de software

**`Descrição:`**
A documentação exigida pela ED2 compete diretamente com o tempo disponível para implementar o sistema.

**`Mitigação:`**
Documentação e desenvolvimento devem caminhar juntos, com responsáveis definidos para atualizar os materiais conforme as entregas avançam.

#### 5.1.05 Baixa previsibilidade na entrega de issues

**`Descrição:`**
Algumas tarefas estão levando mais tempo que o previsto, dificultando o acompanhamento real do projeto.

**`Mitigação:`**
As issues devem ser melhor estimadas e, quando necessário, quebradas em etapas menores com revisão periódica de andamento.

#### 5.1.06 Dependências técnicas entre atividades

**`Descrição:`**
Várias funcionalidades dependem de definições anteriores, como telemetria, banco de dados e validação dos pacotes.

**`Mitigação:`**
As bases do sistema devem ser definidas cedo, e versões simples podem ser usadas para validar a arquitetura antes da solução final.

#### 5.1.07 Dependência da integração com a eletrônica

**`Descrição:`**
Mudanças no protocolo de comunicação afetam backend, banco e interface web.

**`Mitigação:`**
A equipe deve manter comunicação constante entre os núcleos e documentar bem o protocolo, com testes simulados antes da integração real.

#### 5.1.08 Incerteza no fluxo operacional da corrida

**`Descrição:`**
Ainda há indefinição sobre a transição entre mapeamento, rota otimizada e finalização da corrida.

**`Mitigação:`**
Um fluxo mínimo deve ser fechado o quanto antes, para que backend e interface possam avançar com regras estáveis.

#### 5.1.09 Risco na comunicação do Micromouse para o Sistema Web

**`Descrição:`**
O sistema depende do envio estável de pacotes via Wi-Fi/HTTP POST com JSON.

**`Mitigação:`**
A comunicação deve ser validada gradualmente, com pacotes simples no início e tratamento claro de erros no servidor.

#### 5.1.10 Risco de perda de dados de telemetria

**`Descrição:`**
Falhas de rede, de backend ou encerramento inesperado podem comprometer o histórico da corrida.

**`Mitigação:`**
Os dados devem ser salvos de forma incremental, com confirmação de recebimento e mecanismos de reenvio.

#### 5.1.11 Risco de inconsistência na persistência

**`Descrição:`**
Mudanças nos campos enviados ou falta de identificador de corrida podem gerar registros incorretos no banco.

**`Mitigação:`**
A API e o banco devem usar identificador único por corrida e validar os pacotes antes do armazenamento.

#### 5.1.12 Risco de atraso na integração software + hardware

**`Descrição:`**
Se a validação real ficar para o fim, haverá pouco tempo para corrigir incompatibilidades.

**`Mitigação:`**
A integração deve começar assim que possível, mesmo em bancada, para antecipar problemas de comunicação e leitura.

#### 5.1.13 Débito técnico

**`Descrição:`**
A pressão por prazo pode levar a soluções provisórias e pouca revisão, aumentando a chance de bugs.

**`Mitigação:`**
A equipe deve reservar tempo para revisão técnica e registrar claramente quando uma solução for temporária.

#### 5.1.14 Documentação desalinhada com a implementação

**`Descrição:`**
Mudanças no sistema podem não ser refletidas na documentação.

**`Mitigação:`**
Os documentos devem ser atualizados continuamente junto com a implementação, com responsáveis definidos.

#### 5.1.15 Dependência de participação contínua dos responsáveis

**`Descrição:`**
Baixa participação em tarefas específicas pode travar o andamento de outras frentes.

**`Mitigação:`**
As tarefas devem ser conhecidas por mais de um integrante, para facilitar redistribuição em caso de ausência.

### 5.2. Núcleo de Estruturas

#### 5.2.1 Dimensionamento do chassi

**`Descrição:`**
O chassi menor pode gerar incompatibilidade com os componentes internos.

**`Mitigação:`**
O projeto deve ser validado com os demais núcleos, considerando espaço real, encaixes e passagem de cabos.

#### 5.2.2 Acoplamento das rodas

**`Descrição:`**
O acoplamento direto das rodas ao motor pode gerar desalinhamento e imprecisão nos movimentos.

**`Mitigação:`**
Devem ser feitos testes de montagem para verificar alinhamento, atrito e estabilidade do conjunto.

#### 5.2.3 Adequação do suporte dos sensores

**`Descrição:`**
Há risco de erro no posicionamento dos sensores e no desenho do suporte, afetando a leitura.

**`Mitigação:`**
O suporte deve ser testado com medições em bancada para garantir altura, espaçamento e fixação corretos.

#### 5.2.4 Adequação do suporte para PCB

**`Descrição:`**
O suporte das placas precisa manter espaçamento sem prejudicar conexões nem aumentar demais a altura.

**`Mitigação:`**
O encaixe deve ser validado antes da impressão final, considerando cabos, conectores e espaço interno.

#### 5.2.5 Uso da impressora 3D

**`Descrição:`**
A fabricação das peças depende de impressora 3D com boa precisão, o que pode gerar atrasos.

**`Mitigação:`**
A impressão deve ser planejada com antecedência, e peças de teste podem ajudar a validar tolerâncias.

#### 5.2.6 Tempo curto para ajustes antes da entrega 2

**`Descrição:`**
O prazo reduzido limita correções e aumenta o impacto de erros na montagem final.

**`Mitigação:`**
Os testes mais críticos devem ser antecipados, deixando para essa fase apenas ajustes pontuais.

### 5.3. Núcleo de Energia

#### 5.3.1 Cálculo de parâmetros da bateria

**`Descrição:`**
O dimensionamento da bateria precisa atender à demanda do sistema sem comprometer a autonomia.

**`Mitigação:`**
Os consumos devem ser revisados e, sempre que possível, confirmados com medições práticas.

#### 5.3.2 Soldagem da bateria

**`Descrição:`**
A soldagem pode causar danos aos componentes ou riscos aos integrantes se for feita sem cuidado.

**`Mitigação:`**
O processo deve seguir boas práticas de segurança, com atenção à polaridade e à temperatura do ferro.

#### 5.3.3 Adequação do suporte da bateria

**`Descrição:`**
Se a bateria ficar distante da PCB, a conexão pode se tornar difícil ou instável.

**`Mitigação:`**
O suporte deve ser projetado junto com a distribuição interna do robô, validando as distâncias reais.

### 5.4. Núcleo de Eletrônica

#### 5.4.1 Densidade de componentes

**`Descrição:`**
O espaço reduzido exige uma PCB compacta, aumentando o risco de erro no layout.

**`Mitigação:`**
O roteamento e a posição dos componentes devem ser revisados com atenção antes da fabricação.

#### 5.4.2 Integração de telemetria

**`Descrição:`**
A telemetria com interface web precisa funcionar sem atrapalhar o desempenho do robô.

**`Mitigação:`**
A solução deve ser leve e testada gradualmente para não interferir nos algoritmos principais.

#### 5.4.3 Logística para fabricação e envio da PCB

**`Descrição:`**
O prazo de fabricação da placa é um dos principais gargalos do projeto.

**`Mitigação:`**
A PCB deve ser revisada com cuidado antes do envio, para evitar retrabalho e perda de prazo.

#### 5.4.4 Confiabilidade física

**`Descrição:`**
As vibrações do robô podem afetar soldas e conectores se a placa não estiver bem fixada.

**`Mitigação:`**
A PCB deve ser presa de forma firme e testada para suportar o movimento do conjunto.

<br>

## 6. Classificação de risco por núcleo

A *Figura 2* exibe uma contagem visual da classificação dos riscos obtida pelo time.

<p align="center"><i>Figura 2: Análise da classificação de riscos por núcleo</i></p>

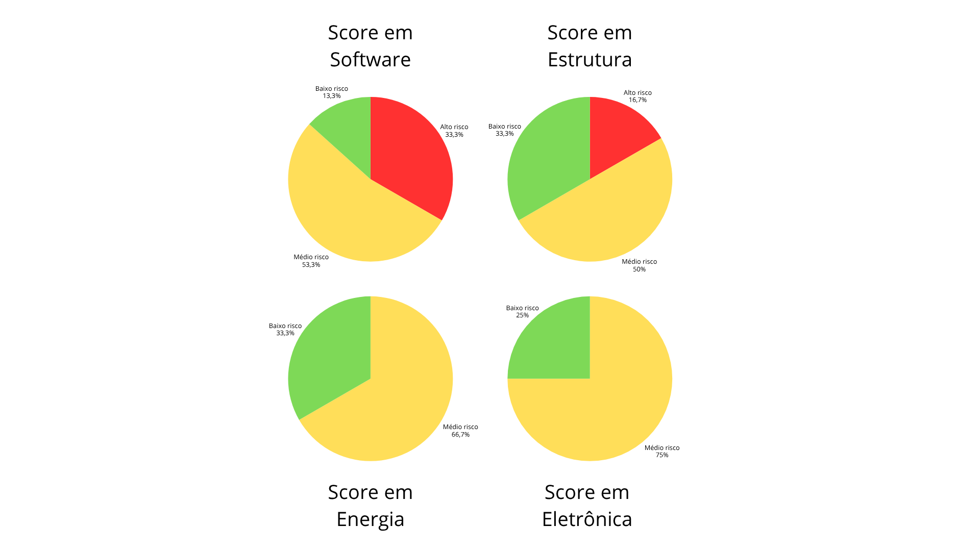
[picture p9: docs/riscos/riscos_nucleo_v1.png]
Plano de Gerênciamento de Riscos


<p align="center"><i>Fonte: Elaboração própria pelo grupo.</i></p>

Observe que, na etapa atual do projeto (Sprints 8 e 9), o levantamento de riscos aponta para maior concentração de problemas de **alto risco** dentro das frentes de Estrutura e de Software. Esse fenômeno pode, de acordo com uma análise do time, indicar que esses núcleos são pontos de interesse para o gerenciamento de riscos. Isso significa, na prática, que o grupo deve direcionar seus esforços na mitigação de riscos envolvendo essas frentes.

Além disso, também é perceptível a semelhança dos gráficos para Energia e Eletrônica. Em ambos os casos, isso pode indicar que os membros dos núcleos em questão conseguiram controlar seus riscos sem que algum deles se sobressaísse como uma preocupação para o resto do grupo. No tópico seguinte, será apresentado um esboço do plano de gerenciamento de riscos para o momento atual do projeto desenvolvido pelo grupo, levando em conta essa análise realizada pelo grupo sobre as métricas obtidas.

## 7. Considerações finais

A análise dos riscos mostra que o sucesso do projeto depende tanto da execução técnica quanto da coordenação entre os núcleos. Como o micromouse possui um espaço físico reduzido, integração complexa e prazo acadêmico limitado, os riscos não devem ser tratados apenas como problemas pontuais, mas como elementos previstos do desenvolvimento. Com acompanhamento contínuo, comunicação entre as áreas e atualizações frequentes do planejamento, além do direcionamento apresentado pelo plano de gerenciamento de riscos, a equipe aumenta a chance de seguir seu planejamento a cada entrega.  

## 8. Tabela de Versionamento

| Versão | Data | Autor | Descrição | Revisor |
| :-: | :-: | :-: | :-: | :-: |
| 1.0 | 05/06/2026 | [Eduardo de Pina](https://github.com/eduardodpms) | Conversão do documento para markdown | [Geovana Almeida](https://github.com/geovanaams) |

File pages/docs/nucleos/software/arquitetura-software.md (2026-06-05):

# Arquitetura de Software

## 1. Visão Geral

O Sistema Web do Micromouse tem como objetivo apoiar o monitoramento, armazenamento e análise dos dados gerados durante as corridas do robô. A solução é responsável por receber dados de telemetria enviados pelo Micromouse, exibir informações em tempo real, persistir resultados das execuções e permitir consultas posteriores.

A arquitetura proposta utiliza uma estrutura monolítica em camadas, adequada ao escopo acadêmico do projeto, separando responsabilidades entre interface web, backend, persistência de dados, comunicação em tempo real e integração com o sistema embarcado.

---

## 2. Propósito do Software

O software atua como camada de apoio ao sistema físico do Micromouse, permitindo que os dados da corrida sejam visualizados, registrados e analisados.

As principais responsabilidades do sistema são:

- receber dados de telemetria do Micromouse;
- validar os dados recebidos;
- exibir informações da corrida em tempo real;
- mostrar indicadores como trajeto, bateria, velocidade média, tempo e status da corrida;
- persistir os dados finais da execução;
- permitir consultas históricas por labirinto;
- permitir consultas gerais das execuções.

---

## 3. Padrão Arquitetural Adotado

A solução adota uma arquitetura monolítica em camadas, composta por:

- Camada de Apresentação;
- Camada de Aplicação;
- Camada de Persistência;
- Mecanismo de Comunicação em Tempo Real.

---

### 3.1 Camada de Apresentação

Responsável pela interface web desenvolvida em React.

### Funções principais

- exibição da telemetria em tempo real;
- visualização do mapa do labirinto;
- apresentação de indicadores da corrida;
- consulta de resultados históricos.

---

### 3.2 Camada de Aplicação

Responsável pelo backend desenvolvido em FastAPI.

### Funções principais

- recebimento da telemetria;
- validação dos dados;
- gerenciamento das sessões de corrida;
- disponibilização de APIs REST;
- distribuição de eventos em tempo real para o frontend.

---

### 3.3 Camada de Persistência

Responsável pelo armazenamento dos dados no PostgreSQL.

### Funções principais

- persistência das corridas;
- armazenamento de telemetria histórica;
- armazenamento dos labirintos;
- consulta de execuções anteriores.

---

### 3.4 Comunicação em Tempo Real

A atualização em tempo real ocorre utilizando WebSocket entre backend e frontend.

O Micromouse envia os dados de telemetria ao backend via Wi‑Fi através de um roteador utilizando HTTP POST com payload JSON. Após validação, o backend redistribui os dados ao frontend utilizando WebSocket.

A atualização visual ocorre em tempo real, enquanto a persistência no banco pode ocorrer em lote para reduzir overhead de escrita.

---

### 3.5 Justificativa Arquitetural

A arquitetura foi escolhida por apresentar:

- menor complexidade de implantação;
- facilidade de desenvolvimento em equipe;
- adequação ao escopo acadêmico;
- suporte adequado à telemetria em tempo real;
- facilidade de manutenção.

Não foram adotadas arquiteturas baseadas em microsserviços devido ao aumento desnecessário da complexidade operacional para o tamanho atual da solução.

---

## 4. Tecnologias Utilizadas

### 4.1 Linguagens

| Camada | Linguagem |
|---|---|
| Frontend | TypeScript (React) |
| Backend | Python |
| Banco de Dados | SQL |
| Firmware | C/C++ |

---

### 4.2 Frameworks e Tecnologias

| Tecnologia | Uso |
|---|---|
| React | Interface web |
| FastAPI | API backend |
| WebSocket | Comunicação em tempo real |
| PostgreSQL | Persistência de dados |
| Uvicorn/ASGI | Execução da aplicação FastAPI |
| ESP-IDF | Desenvolvimento do firmware |
| FreeRTOS | Gerenciamento de tarefas embarcadas |

---

## 5. Organização Geral da Solução

A solução é composta pelos seguintes elementos:

- Micromouse;
- Frontend Web;
- Backend FastAPI;
- Banco PostgreSQL.

---

## Fluxo Principal

1. O Micromouse coleta informações dos sensores.
2. O firmware organiza os dados de telemetria.
3. O Micromouse envia os dados ao backend via HTTP/REST utilizando Wi-Fi.
4. O backend valida os pacotes recebidos.
5. O backend redistribui os dados ao frontend utilizando WebSocket.
6. O frontend atualiza a interface em tempo real.
7. O backend persiste os dados históricos no PostgreSQL.
8. O usuário pode consultar execuções anteriores.

---

## 6. Visões Arquiteturais

A arquitetura do sistema é documentada utilizando uma adaptação do modelo 4+1.

Neste projeto, a visão de casos de uso foi substituída por uma visão de dados, conforme orientação da disciplina.

---

### 6.1 Visão Lógica

A visão lógica descreve os principais módulos da solução de software e suas responsabilidades.

Os módulos principais são:

- **Interface Web:** exibe dados de monitoramento e telas de consulta;
- **Módulo de Telemetria:** recebe e valida os dados enviados pelo Micromouse;
- **Módulo de Monitoramento:** atualiza a interface em tempo real;
- **Módulo de Persistência:** armazena os dados finais das corridas;
- **Módulo de Consulta:** permite visualizar resultados históricos.

### 6.1.1 Comportamento Dinâmico (Diagrama de Estados)

O comportamento do sistema durante o ciclo de uma corrida é regido por estados que garantem a integridade da telemetria e o controle da sessão. O fluxo transita desde a configuração inicial até o salvamento final dos dados no PostgreSQL.

Ele contempla estados como:

- aguardando configuração;
- sessão iniciada;
- aguardando largada;
- mapeamento inicial;
- conexão perdida;
- mapa consolidado;
- cálculo de rota otimizada;
- execução da rota otimizada;
- alerta crítico;
- desafio cumprido;
- desafio não cumprido;
- salvamento dos dados;
- corrida finalizada.

Esse diagrama auxilia na compreensão do comportamento dinâmico do sistema e dos eventos que provocam transições entre estados.

<p style="text-align: center;">
  <em>Figura 2: Diagrama de Estados</em>
</p>

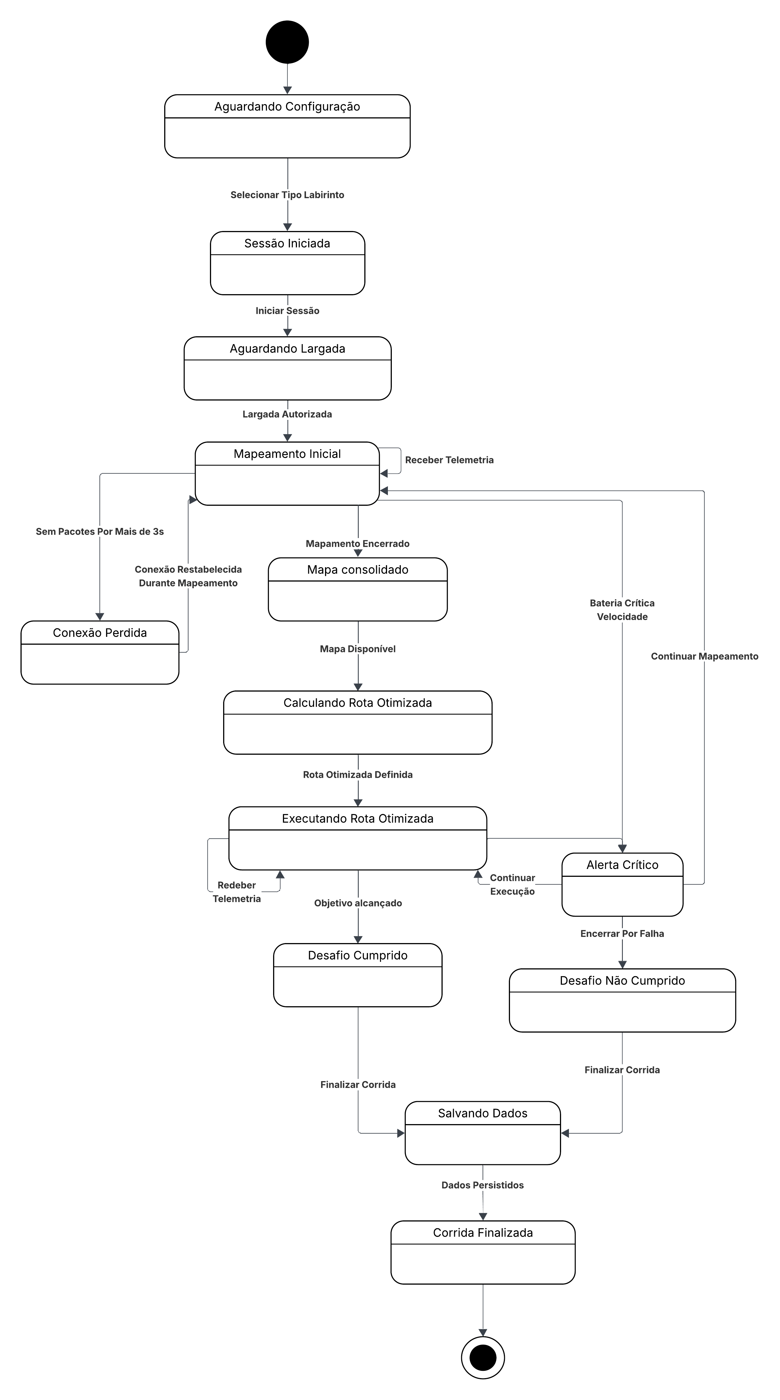
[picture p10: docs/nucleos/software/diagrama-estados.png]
Diagrama de Estados


<div style="text-align: center;">Autor: <a href="https://github.com/Potatoyz908">Euller</a></div>

### 6.1.2 Fluxo Operacional (Diagrama de Atividades UML)

O Diagrama de Atividades detalha o comportamento funcional e a coordenação entre o sistema embarcado e a interface de monitoramento, evidenciando a lógica de controle e o processamento de dados.

#### Estrutura do Diagrama

O fluxo utiliza **Raias (swimlanes)** para delimitar as responsabilidades entre os dois atores principais:

*   **Micromouse (Embarcado):** Responsável pela execução do algoritmo de navegação (Flood Fill), coleta de dados sensoriais (bateria, velocidade, sensores) e transmissão de telemetria.
*   **Sistema Web:** Responsável pela orquestração da sessão, validação de pacotes, interface de usuário e persistência de dados no PostgreSQL.

#### Descrição Detalhada das Atividades

1.  **Início e Decisão de Sessão:** O processo inicia no Sistema Web com a seleção do tipo de labirinto. Um **nó de decisão** garante que a sessão só avance se o labirinto for selecionado e a sessão iniciada corretamente.

2.  **Paralelismo no Micromouse:** Após iniciar a navegação (fronteiras e, quando aplicável, Floodfill), o robô usa uma **barra de bifurcacao (fork)** para executar em paralelo o **processamento do controle do sistema** e o **envio de pacotes de telemetria ao sistema web**.

3.  **Ciclo de Telemetria (Insumos e Resultados):**
    *   **Entrada:** Pacotes de telemetria transmitidos via Bluetooth/Wi-Fi.
    *   **Processamento:** O Sistema Web recebe e valida os pacotes. Caso sejam inválidos (**nó de decisão**), o pacote é descartado com a respectiva sinalização de falha de validação.

4.  **Sincronização e Atualização:** Se os dados forem válidos, o fluxo utiliza uma nova **barra de bifurcação** para atualizar simultaneamente o trajeto no mapa, os indicadores de performance e a checagem de alertas críticos (visuais e sonoros).

5.  **Pontos de Controle e Encerramento:**
    *   O sistema monitora continuamente, através de nós de decisão, se o **Objetivo foi alcançado** ou se houve um **Encerramento Manual** da sessão.
    *   **Saída Final:** Dependendo do desfecho, o status da corrida é alterado para "Desafio Cumprido" ou "Desafio Não Cumprido".
    *   A persistência automática dos dados ocorre no Banco de Dados antes de o fluxo convergir para o **estado final**.

<p style="text-align: center;">
  <em>Figura 3: Diagrama de Atividades UML</em>
</p>

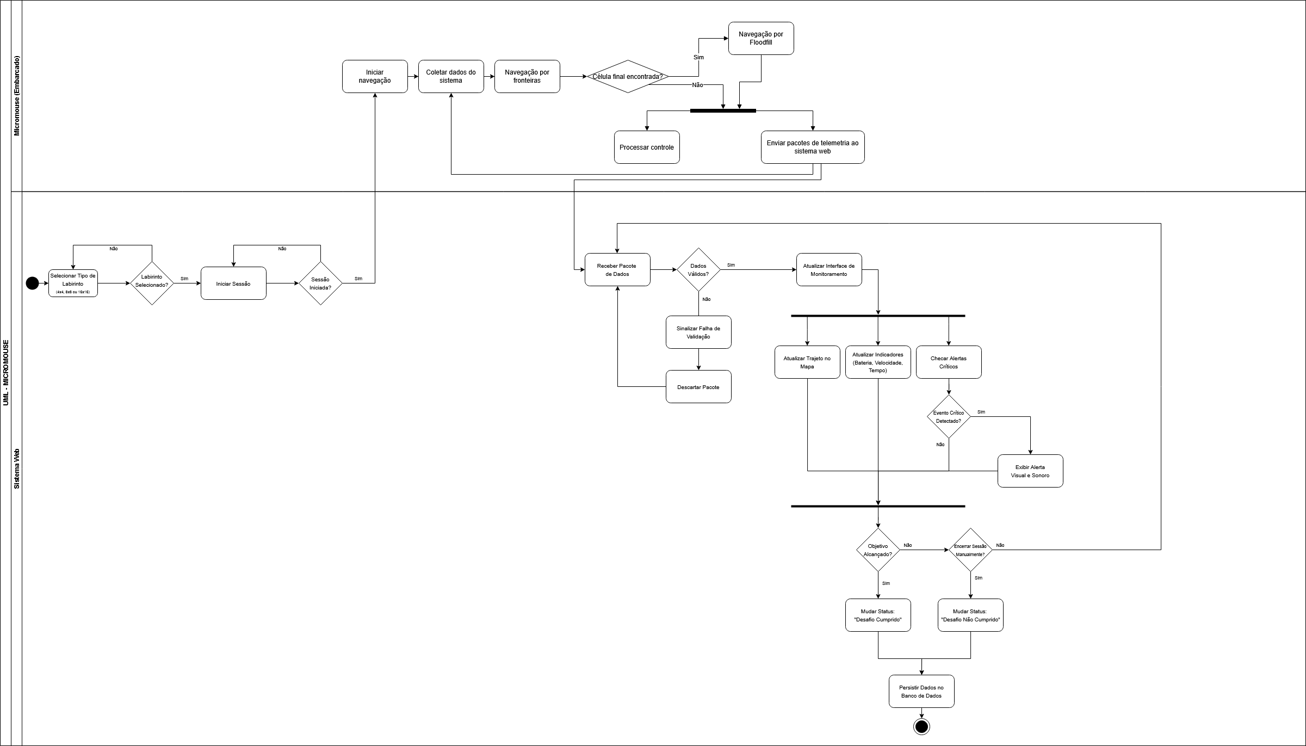
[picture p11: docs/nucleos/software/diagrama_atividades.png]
Diagrama de Atividades UML


<div style="text-align: center;">Autores: <a href="https://github.com/MM4k">Marcelo Makoto</a> <a href="https://github.com/dudaa28">Maria Eduarda</a></div>

---

### 6.1.1 Componentes Web

### Interface Web

Responsável por:

- monitoramento em tempo real;
- visualização do mapa;
- exibição dos indicadores da corrida;
- consulta histórica.

---

### Backend FastAPI

Responsável por:

- recebimento da telemetria;
- validação dos pacotes;
- gerenciamento das sessões;
- persistência dos dados;
- distribuição das atualizações via WebSocket.

---

### 6.1.2 Componentes Embarcados

### Subsistema de Energia

Responsável por:

- alimentação do sistema;
- monitoramento energético;
- regulação de tensão;
- cálculo de carga da bateria.

#### Componentes principais

- bateria Li-Po;
- INA226;
- regulador buck MP1584EN.

---

### Subsistema de Sensoriamento

Responsável por:

- aquisição de dados inerciais;
- medição de distância;
- detecção de obstáculos;
- apoio à navegação.

#### Componentes principais

- MPU-9250;
- 3 sensores VL53L0X.

---

### Subsistema de Atuação e Odometria

Responsável por:

- movimentação do robô;
- controle de velocidade;
- medição de deslocamento;
- controle direcional.

#### Componentes principais

- motores N20;
- encoders;
- TB6612FNG.

---

### Subsistema de Armazenamento

Responsável por:

- armazenamento local de telemetria;
- logging de execução;
- persistência de dados para análise pós-corrida.

#### Componentes principais

- módulo SD Card via SPI.

---

### Subsistema de Comunicação

Responsável por:

- envio de telemetria;
- comunicação com o backend;
- sincronização em tempo real.

#### Tecnologias utilizadas

- Wi-Fi nativa do ESP32;
- HTTP/REST;
- WebSocket.

---

### Firmware de Navegação

Responsável por:

- exploração do labirinto;
- mapeamento;
- cálculo da rota otimizada;
- controle de estados da navegação.

#### Algoritmos utilizados

- Frontier-based Exploration;
- Flood Fill;
- Path Planning.

---

### 6.2 Visão de Processos

A visão de processos descreve o comportamento dinâmico do sistema durante uma corrida.

---

### 6.2.1 Fluxo Operacional

1. O sistema aguarda a configuração da sessão.
2. O usuário seleciona o labirinto.
3. O Micromouse inicializa sensores e motores.
4. O algoritmo de navegação inicia a exploração.
5. O firmware coleta dados dos sensores.
6. A telemetria é enviada ao backend via HTTP/REST.
7. O backend valida os pacotes recebidos.
8. O frontend recebe atualizações em tempo real via WebSocket.
9. O backend persiste os dados históricos.
10. O Micromouse executa a rota otimizada.
11. A sessão é encerrada.

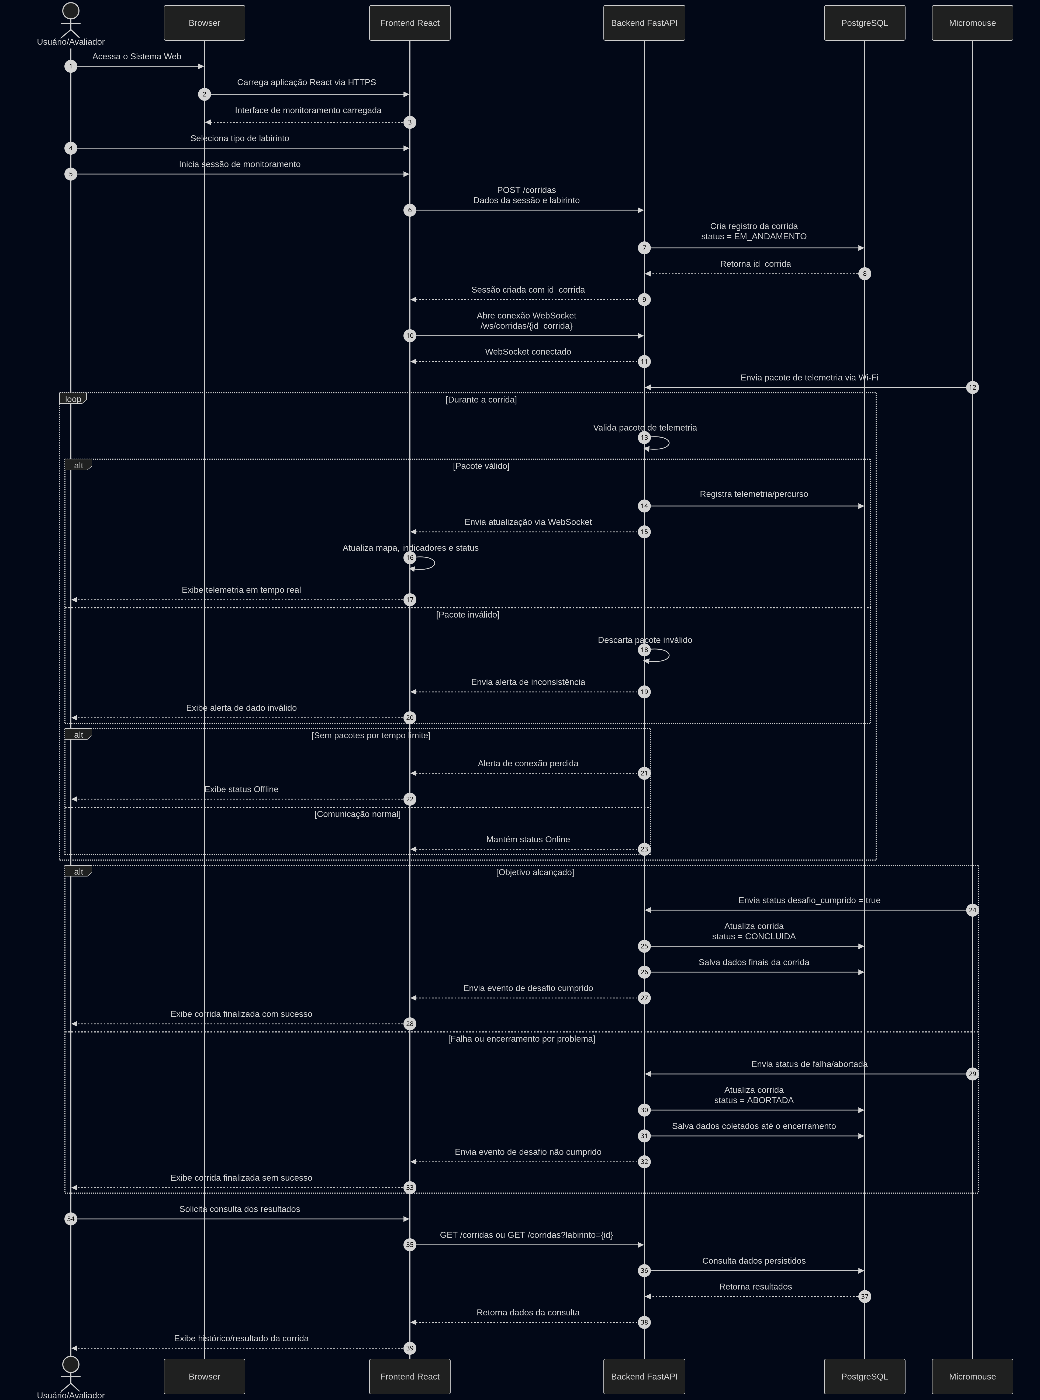
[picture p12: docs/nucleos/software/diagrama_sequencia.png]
Diagrama de Sequência - Ciclo de Vida da Corrida


<div style="text-align: center;">
  Autores:
  <a href="https://github.com/Potatoyz908">Euller</a> e
  <a href="https://github.com/dudaa28">Maria Eduarda</a>
</div>

### 6.2.2 Processos Embarcados

O firmware embarcado executa processos concorrentes utilizando FreeRTOS.

### Tasks principais

| Task | Intervalo | Responsabilidade |
|---|---|---|
| `battery_task` | 500 ms | Monitoramento energético |
| `imu_task` | 100 ms | Leitura da IMU |
| `tof_task` | 200 ms | Leitura dos sensores ToF |
| `motor_task` | 250 ms | Leitura de encoders |
| `data_aggregation_task` | 500 ms | Agregação de telemetria |

---

### 6.2.3 Fluxo de Telemetria

1. Sensores são lidos em tasks independentes.
2. Os dados são agregados em uma estrutura compartilhada.
3. A task de agregação monta a estrutura `RobotData`.
4. Em paralelo, a telemetria é enviada ao backend.
5. O backend valida, processa e persiste os dados.

---

### 6.2.4 Máquina de Estados da Navegação

O sistema embarcado utiliza uma máquina de estados responsável pelas transições de navegação.

### Estados principais

- IDLE;
- FRONTIER;
- FLOODFILL;
- OPTIMAL;
- DONE.

### Fluxo de estados

```text
IDLE → FRONTIER → FLOODFILL → OPTIMAL → DONE
```

---

### 6.2.5 Tratamento de Exceções

O sistema considera:

- perda de conexão;
- falha de validação;
- perda de sensores;
- baixa tensão da bateria;
- encerramento manual;
- falha da corrida.

#### Timeout de Conexão — Detecção de Offline

O sistema considera o robô como **Offline** se nenhum pacote válido for
recebido pelo backend por mais de **3 segundos**.

Comportamento esperado:

- O backend monitora o timestamp do último pacote recebido por sessão ativa.
- Ao detectar ausência superior a 3 segundos, o backend deve:
  - atualizar o estado da sessão para `"conexao_perdida"`;
  - emitir um evento via WebSocket ao frontend com o tipo
    `CONEXAO_PERDIDA`.
- O frontend deve exibir um alerta visual indicando perda de sinal.
- Caso a conexão seja restabelecida (novo pacote válido recebido), o sistema
  retoma o estado anterior normalmente.

> O pacote `heartbeat` foi definido pela equipe de eletrônica exatamente para
> evitar falsos positivos nessa detecção: o ESP32 o envia periodicamente mesmo
> com o robô parado, mantendo a sessão marcada como ativa.

---

### 6.3 Visão de Implementação

A visão de implementação descreve como os componentes são organizados tecnologicamente.

### 6.3.1 Estrutura de Camadas e Pacotes (Diagrama de Pacotes)

O diagrama a seguir apresenta a organização do sistema em camadas (Apresentação, Aplicação e Dados) e os respectivos pacotes/módulos que compõem cada uma delas, detalhando a estrutura lógica descrita acima.

<p style="text-align: center;">
  <em>Figura: Diagrama de Pacotes</em>
</p>

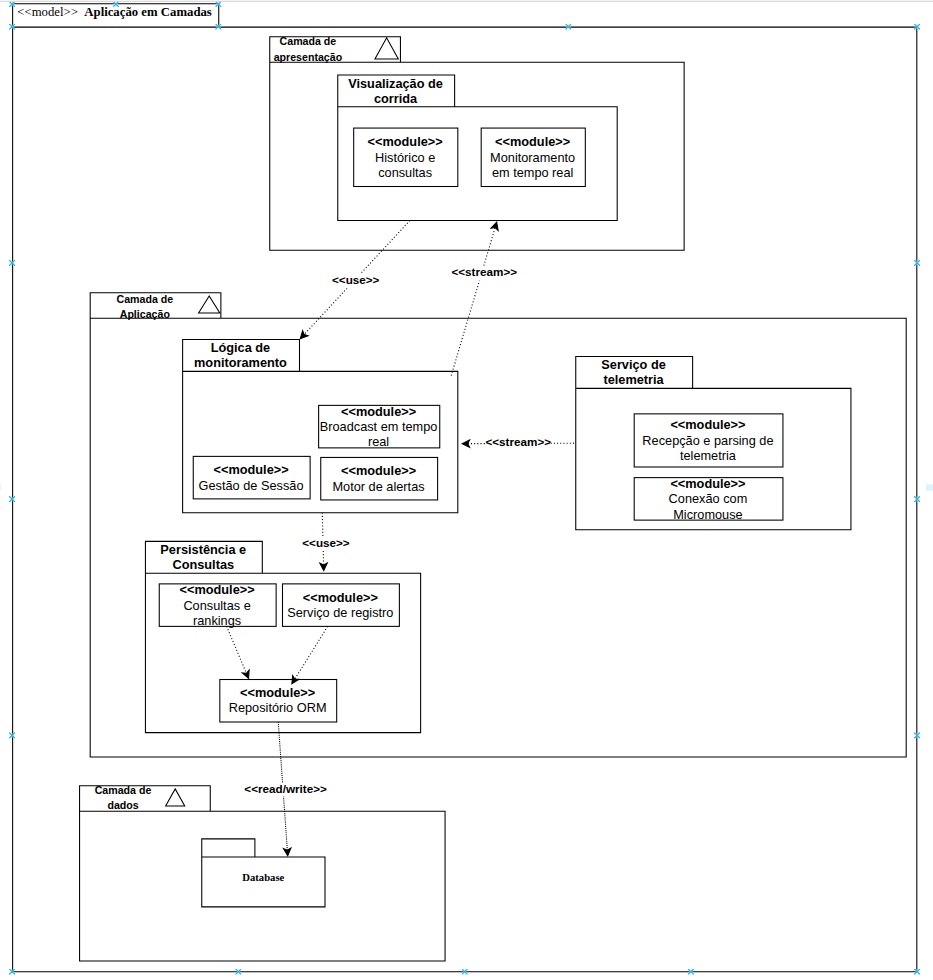
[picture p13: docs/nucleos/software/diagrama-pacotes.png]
Diagrama de Pacotes


<div style="text-align: center;">Autor: <a href="https://github.com/GabrielCastelo-31">Gabriel Castelo</a></div>

### 6.3.1 Frontend

O frontend React é organizado em:

- **Computador do Usuário:** executa o navegador;
- **Servidor Frontend:** disponibiliza a aplicação React;
- **Servidor Backend:** executa a aplicação FastAPI;
- **Fonte de Telemetria:** representa o Micromouse;
- **Servidor de Banco de Dados:** executa o PostgreSQL.

A comunicação entre os nós ocorre por meio dos seguintes protocolos:

- **HTTPS:** comunicação entre navegador e frontend;
- **HTTPS/REST:** comunicação tradicional entre frontend e backend;
- **WSS/WebSocket:** comunicação em tempo real entre frontend e backend;
- **Wi-Fi:** envio de telemetria do Micromouse ao backend;
- **TCP/IP:** comunicação entre backend e banco de dados.

#### Diagrama de Implantação

O diagrama de implantação apresenta uma visão física e tecnológica da solução. Ele mostra onde cada parte do sistema será executada e como os componentes se comunicam.

A arquitetura proposta considera que o usuário acessa o sistema por meio de um navegador. A interface web é desenvolvida em React e se comunica com o backend desenvolvido em FastAPI. O backend recebe os dados do Micromouse, processa a telemetria, envia atualizações em tempo real para o frontend via WebSocket e persiste os dados no PostgreSQL.

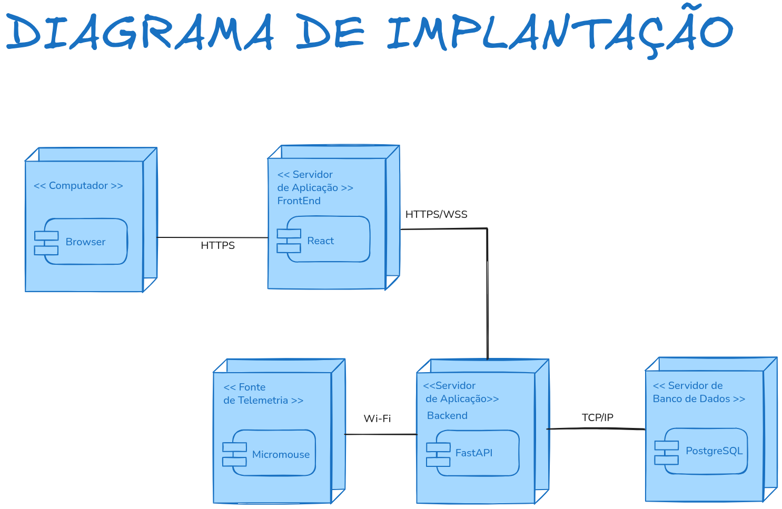
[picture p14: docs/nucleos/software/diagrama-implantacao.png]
Diagrama de Implantação


<div style="text-align: center;">Autor: <a href="https://github.com/Potatoyz908">Euller</a></div>

---
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

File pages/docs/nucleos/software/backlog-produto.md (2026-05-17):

## Backlog do Produto

O *Backlog* do Produto consolida as necessidades e funcionalidades do sistema Micromouse, sendo estruturado para garantir a rastreabilidade e a priorização adequada das entregas. As funcionalidades do sistema foram documentadas diretamente utilizando-se a técnica de Histórias de Usuário (HU), permitindo a compreensão clara das necessidades dos atores sob a perspectiva de valor de negócio.

Para a priorização dos itens, adotou-se o método MoSCoW, classificando as funcionalidades em *Must Have* (essenciais), *Should Have* (importantes, mas não vitais) e *Could Have* (desejáveis). Adicionalmente, os requisitos não-funcionais (RNF) foram definidos sob critérios objetivos, evitando descrições subjetivas e focando em métricas mensuráveis de desempenho, como tempo de resposta e estabilidade da conexão.

Todas as Histórias de Usuário (HUs) possuem descrição estruturada no formato **Eu–Como–Para**, critérios de aceitação e protótipos de interface devidamente documentados. A estrutura completa do Backlog do Produto encontra-se disponível no [Backlog do Projeto no GitHub](https://github.com/orgs/fcte-pi1/projects/16/views/1), permitindo rastreabilidade e acompanhamento detalhado do desenvolvimento do projeto.
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

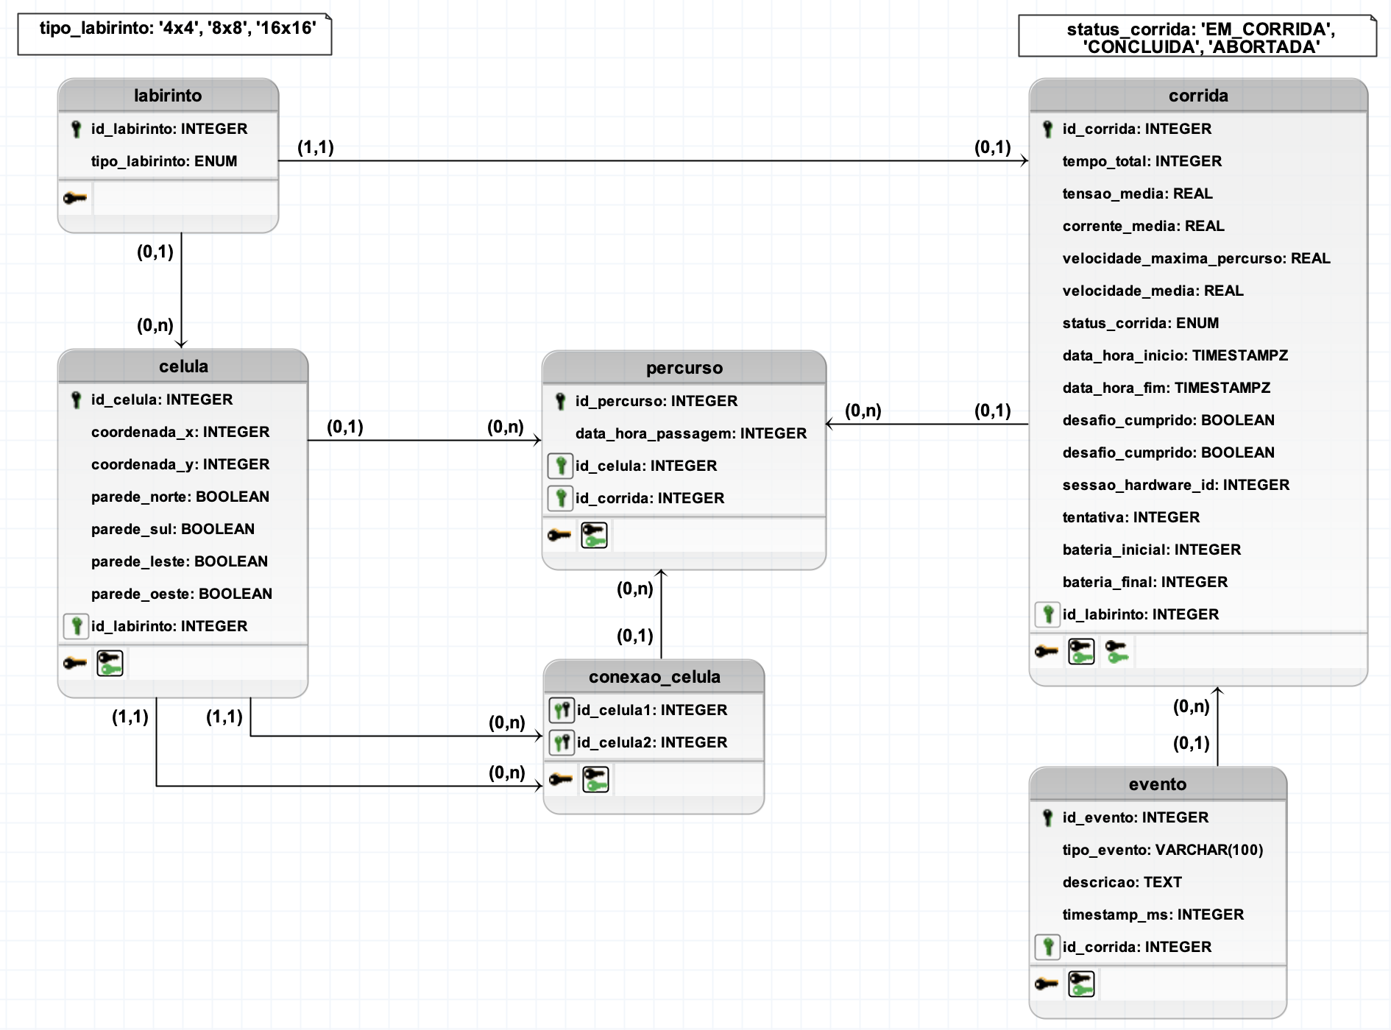
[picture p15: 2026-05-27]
docs/nucleos/software/diagrama_logico_de_dados.png

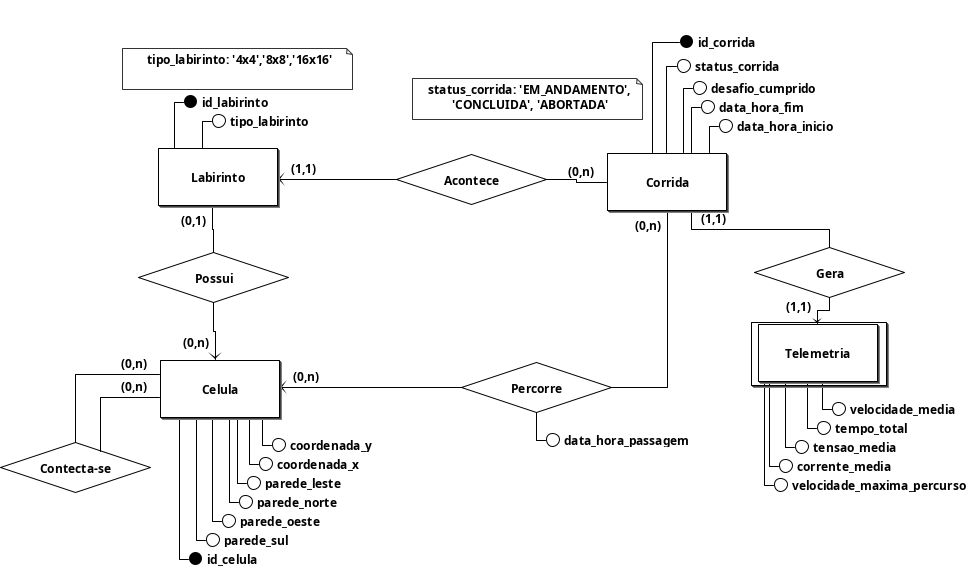
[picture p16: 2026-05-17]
docs/nucleos/software/diagrama_entidade_relacionamento.png

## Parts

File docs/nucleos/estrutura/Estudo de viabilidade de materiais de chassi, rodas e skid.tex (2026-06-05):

\documentclass[12pt, a4paper]{article}
% Estamos usando 12 pacotes
% Estes dois é para codificação de texto
\usepackage[utf8]{inputenc}
\usepackage[T1]{fontenc}
\usepackage{geometry}
\usepackage{amsmath}
\usepackage{array}
\usepackage{booktabs}
\usepackage{url}
\usepackage{helvet}
\usepackage{indentfirst}

\renewcommand{\familydefault}{\sfdefault}

% Este é o comando para por margens
\geometry{top=3cm, bottom=2cm, left=3cm, right=2cm}

% Adiciona espaçamento entre linhas de 1,5 pt
\usepackage{setspace}
\setstretch{1.5}

% Para poder modificar as tabelas
\usepackage{etoolbox}
\AtBeginEnvironment{table}{\setstretch{1.0}\fontsize{10}{12}\selectfont} % ambiente em tabelas
\AtBeginEnvironment{tabular}{\setstretch{1.0}}

% Pacote para personalizar cabeçalhos e rodapés
\usepackage{fancyhdr}
\pagestyle{fancy}
\fancyhf{}
\fancyhead[R]{\thepage}
\renewcommand{\headrulewidth}{0pt}

\setlength{\parindent}{1.25cm}

\newcommand{\fonte}[1]{\vspace{0.2cm}\par\noindent\fontsize{9}{11}\selectfont Fonte: #1}

% Aqui é a capa
\title{Estudo de Viabilidade: Materiais para Chassi, Rodas e Skid \\ 
\large Micromouse - Competição de Robôs Autônomos}
\author{Geovana Almeida Miranda Sant'Ana \\ Caio Venâncio do Rosário}
\date{1 de maio de 2026}

\begin{document}

% a partir daqui tem como gerar seções e subseções no documento
\maketitle

\newpage
\setcounter{page}{2}

\subsection*{Elaboração do estudo}

O presente estudo foi realizado em uma sessão colaborativa na plataforma Discord, com duração total de 5 horas e 28 minutos. Foram responsáveis pela pesquisa, consolidação dos dados e redação final:

\begin{itemize}
    \item Geovana Almeida Miranda Sant'Ana (231027088)
    \item Caio Venâncio do Rosário (231027195)
\end{itemize}

Todo o levantamento de coeficientes de atrito, propriedades térmicas dos materiais e análise de viabilidade técnica e orçamentária foi executado pelos autores durante o período mencionado.

% Seção 1 de introdução e objetivo
\section{Introdução e Objetivo}

Este documento avalia a viabilidade de diferentes materiais poliméricos para três componentes principais de um robô \textit{Micromouse}: \textbf{chassi}, \textbf{rodas} e \textbf{skid} (patim deslizante). O estudo considera três cenários de piso: asfalto (caso extremo de alto atrito), MDF (piso real da competição) e vidro (caso hipotético de baixo atrito).

O robô foi modelado para atingir velocidade de pico de $6 \, m/s$, caracterizando um cenário de alto desempenho. Materiais aprovados neste cenário são automaticamente adequados para robôs mais lentos.

% Seção 2 de metodologia de cálculo térmico
\section{Metodologia de Cálculo Térmico}

A geração de calor por fricção foi estimada pelo modelo de potência dissipada:

\begin{equation}
P = \mu \cdot N \cdot v
\end{equation}

Onde:
\begin{itemize}
    \item $P$ = potência térmica dissipada [W]
    \item $\mu$ = coeficiente de atrito cinético [adimensional]
    \item $N$ = força normal (peso do robô) [N]
    \item $v$ = velocidade [m/s]
\end{itemize}

\textbf{Parâmetros adotados:}
\begin{itemize}
    \item Massa do robô: $m = 0,1 \, kg$ (100 gramas)
    \item Força normal: $N = m \cdot g = 0,1 \cdot 9,81 = 0,981 \, N \approx 1 \, N$
    \item Velocidade: $v = 6 \, m/s$
\end{itemize}

A Tabela \ref{tab:potencia} apresenta a potência gerada para diferentes coeficientes de atrito.
\begin{table}[h]
\centering
\caption{Potência térmica gerada por fricção a 6 m/s}
\label{tab:potencia}
\begin{tabular}{c|c}
\hline
$\mu$ & $P$ (W) \\ \hline
0,05 & 0,30 \\
0,10 & 0,60 \\
0,30 & 1,80 \\
0,50 & 3,00 \\
0,70 & 4,20 \\ \hline
\end{tabular}
\fonte{Elaboração própria (2026).}
\end{table}

\subsection*{Critério de Falha Térmica}

Um material falha quando sua superfície atinge a \textbf{Temperatura de Transição Vítrea} ($T_g$), passando do estado rígido ao borrachudo, perdendo forma e aumentando o atrito irreversivelmente. Para elastômeros (TPU), a $T_g$ não é definida, sendo mais resistentes.

% Seção 3 de análise de coeficientes de atrito por superfície
\section{Análise de Coeficientes de Atrito por Superfície}

A Tabela \ref{tab:coef_atrito} apresenta os coeficientes de atrito estimados para cada material nas três superfícies analisadas.
\begin{table}[h]
\centering
\caption{Coeficientes de atrito estimados por material e superfície}
\label{tab:coef_atrito}
\begin{tabular}{l|c|c|c}
\hline
\textbf{Material} & \textbf{Asfalto} & \textbf{MDF} & \textbf{Vidro} \\ \hline
PLA & 0,4 - 0,5 & 0,5 - 0,6 & 0,3 - 0,4 \\
PETG & 0,3 - 0,4 & 0,4 - 0,5 & 0,15 - 0,25 \\
ABS & 0,5 - 0,6 & 0,4 - 0,55 & 0,2 - 0,3 \\
ASA & 0,5 - 0,6 & 0,4 - 0,55 & 0,2 - 0,3 \\
Nylon & 0,4 - 0,5 & 0,3 - 0,45 & 0,15 - 0,25 \\
TPU & 0,6 - 0,8 & 0,5 - 0,7 & 0,5 - 0,6 \\
PTFE (fita) & 0,05 - 0,10 & 0,04 - 0,08 & 0,04 - 0,07 \\ \hline
\end{tabular}
\fonte{Elaboração própria a partir de dados estimados (2026).}
\end{table}

% Seção 4 de risco de falha térmica
\section{Risco de Falha Térmica a 6 m/s}

A Tabela \ref{tab:falha} avalia o risco de derretimento/deformação para cada material na velocidade máxima.
\begin{table}[h]
\centering
\caption{Risco de falha térmica a 6 m/s}
\label{tab:falha}
\begin{tabular}{l|c|c}
\hline
\textbf{Material} & $T_g$ (°C) & \textbf{Risco de Falha} \\ \hline
PLA & 60 - 65 & ALTO (excede $T_g$ rapidamente) \\
PETG & 75 - 85 & MODERADO-ALTO \\
ABS & 105 - 115 & MODERADO \\
ASA & 110 - 120 & MODERADO \\
Nylon & 45 - 70* & MODERADO-ALTO (*$T_g$ baixa mas tenacidade alta) \\
TPU & --- & BAIXO (elastômero, dissipa bem) \\
PTFE & $>$300 & MUITO BAIXO \\ \hline
\end{tabular}
\fonte{Elaboração própria com base em fichas técnicas (2026).}
\end{table}

% Seção 5 de aplicação por componente
\section{Aplicação por Componente}

\subsection{Chassi}

Requisitos: rigidez, resistência ao impacto, baixa deformação térmica.

\begin{table}[h]
\centering
\caption{Materiais para chassi - ordem de preferência}
\label{tab:chassi}
\begin{tabular}{l|c}
\hline
\textbf{Material} & \textbf{Desempenho} \\ \hline
ASA & Excelente (rígido, estável, fácil de imprimir) \\
ABS & Bom (similar ao ASA, porém menos estável) \\
PETG & Regular (mais flexível, pode torcer) \\
PLA & Péssimo (frágil, deforma com calor) \\
TPU & Inadequado (muito flexível) \\ \hline
\end{tabular}
\fonte{Elaboração própria (2026).}
\end{table}

\subsection{Rodas Motorizadas}

Requisitos: alto atrito para aceleração e frenagem.

\begin{table}[h]
\centering
\caption{Materiais para rodas - ordem de preferência}
\label{tab:rodas}
\begin{tabular}{l|c}
\hline
\textbf{Material} & \textbf{Desempenho} \\ \hline
TPU & Excelente (maior $\mu$, dissipa calor bem) \\
ABS/ASA & Bom (atrito médio-alto, alternativas rígidas) \\
PLA/PETG & Não recomendado (falha térmica ou baixo atrito) \\ \hline
\end{tabular}
\fonte{Elaboração própria (2026).}
\end{table}

\subsection{Skid (Patim Deslizante)}

Requisitos: mínimo atrito, alta resistência ao desgaste.

\begin{table}[h]
\centering
\caption{Materiais para skid - ordem de preferência}
\label{tab:skid}
\begin{tabular}{l|c}
\hline
\textbf{Material} & \textbf{Desempenho} \\ \hline
Fita PTFE (Teflon) & Excelente ($\mu \approx 0,05$) \\
POM (Acetal/Delrin) & Ótimo ($\mu \approx 0,13$) \\
Nylon & Regular ($\mu \approx 0,34$) \\
ASA/ABS & Péssimo ($\mu \approx 0,5$) \\ \hline
\end{tabular}
\fonte{Elaboração própria (2026).}
\end{table}

% Seção 6 de recomendação final para o projeto
\section{Recomendação Final para o Projeto}

Considerando:
\begin{itemize}
    \item Impressora disponível: Bambu Lab X1 Carbon (câmara fechada)
    \item Orçamento: R\$ 100 por pessoa (20 pessoas = R\$ 2.000 total)
    \item Desejo de usar \textbf{um único filamento} para chassi + skid
    \item Rodas adquiridas separadamente (Lego ou comerciais)
    \item Evitar compósitos devido à anisotropia
\end{itemize}

\subsection*{Material Escolhido: ASA (Acrilonitrila Estireno Acrilato)}

\begin{table}[h]
\centering
\caption{Justificativa para escolha do ASA}
\label{tab:justificativa}
\begin{tabular}{l|l}
\hline
\textbf{Critério} & \textbf{Avaliação} \\ \hline
Custo (1kg) & R\$ 120 - 150 \\
Chassi & Excelente (rígido, resistente ao calor) \\
Skid (puro) & Ruim (alto atrito) \\
Skid + fita PTFE & Excelente (solução híbrida) \\
Impressão na X1 Carbon & Ideal (câmara fechada) \\
Anisotropia & Baixa (diferente de compósitos) \\ \hline
\end{tabular}
\fonte{Elaboração própria (2026).}
\end{table}

\subsection*{Solução Proposta}

\begin{enumerate}
    \item Imprimir \textbf{chassi} em ASA.
    \item Imprimir \textbf{skid} em ASA.
    \item Colar \textbf{fita de PTFE} (R\$ 41,46 por 2 rolos) na superfície de contato do skid.
    \item Adquirir \textbf{rodas prontas} (Lego ou rodízios comerciais).
\end{enumerate}

% Seção 7 de Orçamento estimado
\section{Orçamento Estimado (20 pessoas)}

\begin{table}[h]
\centering
\caption{Orçamento detalhado}
\label{tab:orcamento}
\begin{tabular}{l|c}
\hline
\textbf{Item} & \textbf{Valor (R\$)} \\ \hline
2 kg de ASA (2 rolos de 1kg) & 300 \\
Fita PTFE (2 rolos) & 42 \\
Rodas/rodízios (opção econômica) & $\sim$ 50 \\
\textbf{Total} & $\sim$ 392 \\ \hline
\end{tabular}
\fonte{Elaboração própria com base em cotações (2026).}
\end{table}

\textit{Obs: Orçamento muito abaixo do limite de R\$100/pessoa, permitindo folga para componentes eletrônicos.}

% Seção 8 de Conclusão
\section{Conclusão}

A combinação \textbf{ASA + fita PTFE} atende a todos os requisitos:
\begin{itemize}
    \item Chassi rígido e resistente termicamente.
    \item Skid de baixíssimo atrito com a fita.
    \item Custo acessível para o grupo.
    \item Aproveitamento máximo da impressora Bambu Lab X1 Carbon.
\end{itemize}

Alternativa secundária: \textbf{ABS} (mais barato, porém menos estável dimensionalmente) ou \textbf{PETG} (mais fácil de imprimir, porém chassi menos rígido).

\newpage

\begin{thebibliography}{99}

\bibitem{CALLISTER} CALLISTER, W. D.; RETHWISCH, D. G. \textit{Materials Science and Engineering: An Introduction}. 10. ed. Hoboken: Wiley, 2018.

\bibitem{MATWEB} MATWEB. \textit{Propriedades de materiais poliméricos}. Disponível em: \url{www.matweb.com}. Acesso em: 30 abr. 2026.

\bibitem{3DLAB} 3D LAB. \textit{Fichas técnicas de filamentos ASA, ABS, PETG, PLA, TPU, Nylon}. Disponível em: \url{www.3dlab.com.br}. Acesso em: 30 abr. 2026.

\bibitem{BAMBU} BAMBU LAB. \textit{Especificações da impressora X1 Carbon}. Disponível em: \url{www.bambulab.com}. Acesso em: 30 abr. 2026.

\bibitem{IEEE} IEEE ROBOTICS AND AUTOMATION SOCIETY. \textit{IEEE Micromouse Competition: Rules and Guidelines}. Nova York: IEEE, 2023.

\end{thebibliography}

\newpage

% Seção de Anexo A para compra de componentes a parte
\section*{ANEXO A — Levantamento de Componentes para Skid, Esferas e Rodízios}

Como parte do estudo de viabilidade, foram levantadas opções tanto para \textbf{manufatura própria (impressão 3D)} quanto para \textbf{aquisição comercial} de componentes de baixo atrito ou rolamento. Os preços foram cotados em dólares (US\$) ou reais (R\$) conforme a origem.

\subsection*{Opções para impressão própria (Thingiverse)}

\begin{itemize}
    \item \textbf{Suporte para esfera / caster caseiro} – arquivo com geometria para alojar esfera de rolamento.  
    \url{https://www.thingiverse.com/thing:8959}

    \item \textbf{Skid fixo com base para fixação} – modelo simples de patim deslizante para impressão em ABS/ASA ou nylon.  
    \url{https://www.thingiverse.com/thing:3145120}
\end{itemize}

Ambos os projetos podem ser impressos com o filamento ASA escolhido e, se necessário, receber a fita de PTFE na superfície de contato.

\subsection*{Componentes comerciais avaliados}

\subsubsection*{Rodízios adesivos (mini casters)}

\begin{itemize}
    \item \textbf{VXB – 1/2" Mini Swivel Adhesive Caster Wheels (pacote com 8)}  
    Pequenos rodízios giratórios com placa autoadesiva.  
    \url{https://vxb.com/products/1-2in-mini-swivel-adhesive-caster-wheels-8pack}

    \item \textbf{GNYOHUA – Self-Adhesive Casters (Amazon EUA)}  
    Modelo similar, com 8 peças, aplicação leve.  
    \url{https://www.amazon.com/GNYOHUA-Adhesive-Furniture-Appliances-Light-Duty/dp/B0CXPQSC9R}  
    \textbf{Preço:} US\$ 9,99 + frete de importação.
\end{itemize}

\subsubsection*{Múltiplas esferas ou esfera única}

\begin{itemize}
    \item \textbf{Esfera única para móvel (transferidor universal)} – pode ser adaptada como ponto de contato de baixo atrito.  
    \url{https://www.amazon.com/Appliance-Universal-Transfers-Furniture-Appliances/dp/B0D8PHFKRQ}  
    \textbf{Preço:} US\$ 8,49.
\end{itemize}

\subsubsection*{Fita de PTFE (baixíssimo atrito)}

\begin{itemize}
    \item \textbf{Fita deslizante para gaveta – 1,5 cm x 10 m (2 rolos)}  
    Material: PTFE, resistente à abrasão e ao calor. Disponível na Amazon Brasil.  
    \textbf{Preço:} R\$ 41,46 (2 rolos).
\end{itemize}

\subsection*{Análise de custo-benefício}

\begin{table}[h]
\centering
\caption{Comparativo entre soluções para baixo atrito}
\label{tab:comp_solucoes}
\begin{tabular}{l|c|c|c}
\hline
\textbf{Solução} & \textbf{Atrito estimado} & \textbf{Custo (R\$)} & \textbf{Observação} \\ \hline
Fita PTFE + skid impresso & Muito baixo ($\mu \approx 0,05$) & 20-30 & Mais flexível e barato \\
Caster adesivo (8 unid.) & Baixo (rolamento) & $\approx$ 60-80 & Bom, mas mais caro \\
Esfera única (móvel) & Baixo (rolamento) & $\approx$ 50 & Útil para pontos localizados \\ \hline
\end{tabular}
\fonte{Elaboração própria com base em cotações (2026).}
\end{table}

A fita de PTFE com skid impresso foi a opção selecionada por apresentar o menor custo total, maior adaptabilidade geométrica e coeficiente de atrito mais baixo entre todas as alternativas.

\end{document}

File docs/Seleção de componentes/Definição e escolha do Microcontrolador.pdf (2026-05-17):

# Definição e escolha do Microcontrolador

Após a análise das necessidades do projeto do Micromouse, foi definido o seguinte componente:

- Microcontrolador: ESP32 DevKit

A escolha do ESP32 DevKit baseou-se em critérios técnicos e práticos, resolvendo as principais necessidades de processamento, conectividade e integração de hardware do projeto.

### 1. Explicação da escolha do Microcontrolador

O Micromouse exige um processamento rápido para o mapeamento do labirinto e grande capacidade de integração simultânea com diversos sensores e motores. Desse modo, as seguintes características foram fundamentais para a escolha do ESP32 como o microcontrolador para o projeto:

- Processamento e Memória: O processador dual-core e a ampla disponibilidade de memória SRAM são essenciais para executar algoritmos complexos de mapeamento e resolução de labirintos de forma rápida e eficiente, sem gargalos de memória.
- Ecossistema e Validação: Trata-se de um hardware amplamente validado e utilizado por diversas equipes de competição. A vasta disponibilidade de bibliotecas prontas facilita o desenvolvimento do software e a integração ágil dos módulos que utilizaremos.
- Conectividade Integrada: A arquitetura da placa já possui conectividade Wi-Fi e Bluetooth integradas de forma nativa. Isso elimina a necessidade de adquirir periféricos extras para comunicação sem fio e telemetria, o que barateia e simplifica a lista de componentes do projeto.
- Integração I2C: O ESP32 possui integração nativa e eficiente com o protocolo I2C. Essa interface facilita a comunicação com a grande maioria dos módulos escolhidos para o projeto, permitindo que múltiplos dispositivos sejam conectados compartilhando os mesmos pinos de barramento.
- Disponibilidade de Pinos: A placa possui uma quantidade considerável de pinos de entrada e saída, o que confere a flexibilidade necessária para gerenciar várias funções e periféricos de forma simultânea e centralizada.

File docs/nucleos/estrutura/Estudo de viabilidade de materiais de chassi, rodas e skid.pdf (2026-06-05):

Estudo de Viabilidade: Materiais para Chassi,

# Rodas e Skid

### Micromouse - Competição de Robôs Autônomos

### Geovana Almeida Miranda Sant’Ana Caio Venâncio do Rosário

### 1 de maio de 2026

### Elaboração do estudo

O presente estudo foi realizado em uma sessão colaborativa na plataforma Dis-

cord, com duração total de 5 horas e 28 minutos. Foram responsáveis pela pesquisa,

consolidação dos dados e redação final:

- Geovana Almeida Miranda Sant’Ana (231027088)
- Caio Venâncio do Rosário (231027195)

Todo o levantamento de coeficientes de atrito, propriedades térmicas dos ma-

teriais e análise de viabilidade técnica e orçamentária foi executado pelos autores

durante o período mencionado.

## 1 Introdução e Objetivo

Este documento avalia a viabilidade de diferentes materiais poliméricos para

três componentes principais de um robô Micromouse: chassi, rodas e skid (patim

deslizante). O estudo considera três cenários de piso: asfalto (caso extremo de alto

atrito), MDF (piso real da competição) e vidro (caso hipotético de baixo atrito).

O robô foi modelado para atingir velocidade de pico de 6 m/s, caracterizando

um cenário de alto desempenho. Materiais aprovados neste cenário são automatica-

mente adequados para robôs mais lentos.

## 2 Metodologia de Cálculo Térmico

A geração de calor por fricção foi estimada pelo modelo de potência dissipada:

P = µ · N · v | (1)

Onde:

- P = potência térmica dissipada [W]
- µ = coeficiente de atrito cinético [adimensional]

- N = força normal (peso do robô) [N]
- v = velocidade [m/s]

Parâmetros adotados:

- Massa do robô: m = 0, 1 kg (100 gramas)
- Força normal: N = m · g = 0, 1 · 9, 81 = 0, 981 N ≈ 1 N
- Velocidade: v = 6 m/s

A Tabela 1 apresenta a potência gerada para diferentes coeficientes de atrito.

Table 1: Potência térmica gerada por fricção a 6 m/s
µ | P (W)
0,05 | 0,30
0,10 | 0,60
0,30 | 1,80
0,50 | 3,00
0,70 | 4,20

Fonte: Elaboração própria (2026).

### Critério de Falha Térmica

Um material falha quando sua superfície atinge a Temperatura de Transição

Vítrea (Tg), passando do estado rígido ao borrachudo, perdendo forma e aumentando

o atrito irreversivelmente. Para elastômeros (TPU), a Tg não é definida, sendo mais

resistentes.

## 3 Análise de Coeficientes de Atrito por Superfície

A Tabela 2 apresenta os coeficientes de atrito estimados para cada material nas

três superfícies analisadas.

## 4 Risco de Falha Térmica a 6 m/s

A Tabela 3 avalia o risco de derretimento/deformação para cada material na

velocidade máxima.

Table 2: Coeficientes de atrito estimados por material e superfície
Material | Asfalto | MDF | Vidro
PLA | 0,4 - 0,5 | 0,5 - 0,6 | 0,3 - 0,4
PETG | 0,3 - 0,4 | 0,4 - 0,5 | 0,15 - 0,25
ABS | 0,5 - 0,6 | 0,4 - 0,55 | 0,2 - 0,3
ASA | 0,5 - 0,6 | 0,4 - 0,55 | 0,2 - 0,3
Nylon | 0,4 - 0,5 | 0,3 - 0,45 | 0,15 - 0,25
TPU | 0,6 - 0,8 | 0,5 - 0,7 | 0,5 - 0,6
PTFE (fita) | 0,05 - 0,10 | 0,04 - 0,08 | 0,04 - 0,07

Fonte: Elaboração própria a partir de dados estimados (2026).

Table 3: Risco de falha térmica a 6 m/s
Material | Tg (°C) | Risco de Falha
PLA | 60 - 65 | ALTO (excede Tg rapidamente)
PETG | 75 - 85 | MODERADO-ALTO
ABS | 105 - 115 | MODERADO
ASA | 110 - 120 | MODERADO
Nylon | 45 - 70* | MODERADO-ALTO (*Tg baixa mas tenacidade alta)
TPU | — | BAIXO (elastômero, dissipa bem)
PTFE | >300 | MUITO BAIXO

Fonte: Elaboração própria com base em fichas técnicas (2026).

## 5 Aplicação por Componente

### 5.1 Chassi

Requisitos: rigidez, resistência ao impacto, baixa deformação térmica.

Table 4: Materiais para chassi - ordem de preferência
Material | Desempenho
ASA | Excelente (rígido, estável, fácil de imprimir)
ABS | Bom (similar ao ASA, porém menos estável)
PETG | Regular (mais flexível, pode torcer)
PLA | Péssimo (frágil, deforma com calor)
TPU | Inadequado (muito flexível)

Fonte: Elaboração própria (2026).

### 5.2 Rodas Motorizadas

Requisitos: alto atrito para aceleração e frenagem.

Table 5: Materiais para rodas - ordem de preferência
Material | Desempenho
TPU | Excelente (maior µ, dissipa calor bem)
ABS/ASA | Bom (atrito médio-alto, alternativas rígidas)
PLA/PETG | Não recomendado (falha térmica ou baixo atrito)

Fonte: Elaboração própria (2026).

### 5.3 Skid (Patim Deslizante)

Requisitos: mínimo atrito, alta resistência ao desgaste.

Table 6: Materiais para skid - ordem de preferência
Material | Desempenho
Fita PTFE (Teflon) | Excelente (µ ≈ 0, 05)
POM (Acetal/Delrin) | Ótimo (µ ≈ 0, 13)
Nylon | Regular (µ ≈ 0, 34)
ASA/ABS | Péssimo (µ ≈ 0, 5)

Fonte: Elaboração própria (2026).

## 6 Recomendação Final para o Projeto

Considerando:

- Impressora disponível: Bambu Lab X1 Carbon (câmara fechada)
- Orçamento: R$ 100 por pessoa (20 pessoas = R$ 2.000 total)
- Desejo de usar um único filamento para chassi + skid
- Rodas adquiridas separadamente (Lego ou comerciais)
- Evitar compósitos devido à anisotropia

### Material Escolhido: ASA (Acrilonitrila Estireno Acrilato)

### Solução Proposta

1. Imprimir chassi em ASA.
2. Imprimir skid em ASA.

Table 7: Justificativa para escolha do ASA
Critério | Avaliação
Custo (1kg) | R$ 120 - 150
Chassi | Excelente (rígido, resistente ao calor)
Skid (puro) | Ruim (alto atrito)
Skid + fita PTFE | Excelente (solução híbrida)
Impressão na X1 Carbon | Ideal (câmara fechada)
Anisotropia | Baixa (diferente de compósitos)

Fonte: Elaboração própria (2026).

3. Colar fita de PTFE (R$ 41,46 por 2 rolos) na superfície de contato do skid.
4. Adquirir rodas prontas (Lego ou rodízios comerciais).

## 7 Orçamento Estimado (20 pessoas)

Table 8: Orçamento detalhado
Item | Valor (R$)
2 kg de ASA (2 rolos de 1kg) | 300
Fita PTFE (2 rolos) | 42
Rodas/rodízios (opção econômica) | ∼ 50
Total | ∼ 392

Fonte: Elaboração própria com base em cotações (2026).

Obs: Orçamento muito abaixo do limite de R$100/pessoa, permitindo folga para

componentes eletrônicos.

## 8 Conclusão

A combinação ASA + fita PTFE atende a todos os requisitos:

- Chassi rígido e resistente termicamente.
- Skid de baixíssimo atrito com a fita.
- Custo acessível para o grupo.
- Aproveitamento máximo da impressora Bambu Lab X1 Carbon.

Alternativa secundária: ABS (mais barato, porém menos estável dimensional-

mente) ou PETG (mais fácil de imprimir, porém chassi menos rígido).

## References

[1] CALLISTER, W. D.; RETHWISCH, D. G. Materials Science and Engineering: An

Introduction. 10. ed. Hoboken: Wiley, 2018.

[2] MATWEB. Propriedades de materiais poliméricos. Disponível em: www.matweb.

com. Acesso em: 30 abr. 2026.

[3] 3D LAB. Fichas técnicas de filamentos ASA, ABS, PETG, PLA, TPU, Nylon.

Disponível em: www.3dlab.com.br. Acesso em: 30 abr. 2026.

[4] BAMBU LAB. Especificações da impressora X1 Carbon. Disponível em: www.

bambulab.com. Acesso em: 30 abr. 2026.

[5] IEEE ROBOTICS AND AUTOMATION SOCIETY. IEEE Micromouse Competition:

Rules and Guidelines. Nova York: IEEE, 2023.

ANEXO A — Levantamento de Componentes para Skid,

## Esferas e Rodízios

Como parte do estudo de viabilidade, foram levantadas opções tanto para man-

ufatura própria (impressão 3D) quanto para aquisição comercial de componentes

de baixo atrito ou rolamento. Os preços foram cotados em dólares (US$) ou reais (R$)

conforme a origem.

### Opções para impressão própria (Thingiverse)

- Suporte para esfera / caster caseiro – arquivo com geometria para alojar esfera

de rolamento. https://www.thingiverse.com/thing:8959

- Skid fixo com base para fixação – modelo simples de patim deslizante para im-

pressão em ABS/ASA ou nylon. https://www.thingiverse.com/thing:3145120

Ambos os projetos podem ser impressos com o filamento ASA escolhido e, se

necessário, receber a fita de PTFE na superfície de contato.

### Componentes comerciais avaliados

Rodízios adesivos (mini casters)

- VXB – 1/2" Mini Swivel Adhesive Caster Wheels (pacote com 8) Pequenos

rodízios giratórios com placa autoadesiva. https://vxb.com/products/1-2in-mini-swivel-adhesive-caster-wheels-8pack

- GNYOHUA – Self-Adhesive Casters (Amazon EUA) Modelo similar, com 8

peças, aplicação leve. https://www.amazon.com/GNYOHUA-Adhesive-Furniture-Appliances-Light-Duty/

dp/B0CXPQSC9R Preço: US$ 9,99 + frete de importação.

Múltiplas esferas ou esfera única

- Esfera única para móvel (transferidor universal) – pode ser adaptada como

ponto de contato de baixo atrito. https://www.amazon.com/Appliance-Universal-Transfers-Furniture-Appliances/

dp/B0D8PHFKRQ Preço: US$ 8,49.

Fita de PTFE (baixíssimo atrito)

- Fita deslizante para gaveta – 1,5 cm x 10 m (2 rolos) Material: PTFE, re-

sistente à abrasão e ao calor. Disponível na Amazon Brasil. Preço: R$ 41,46 (2

rolos).

### Análise de custo-benefício

Table 9: Comparativo entre soluções para baixo atrito
Solução | Atrito estimado | Custo (R$) | Observação
Fita PTFE + skid impresso | Muito baixo (µ ≈ 0, 05) | 20-30 | Mais flexível e barato
Caster adesivo (8 unid.) | Baixo (rolamento) | ≈ 60-80 | Bom, mas mais caro
Esfera única (móvel) | Baixo (rolamento) | ≈ 50 | Útil para pontos localizados

Fonte: Elaboração própria com base em cotações (2026).

A fita de PTFE com skid impresso foi a opção selecionada por apresentar o

menor custo total, maior adaptabilidade geométrica e coeficiente de atrito mais baixo

entre todas as alternativas.

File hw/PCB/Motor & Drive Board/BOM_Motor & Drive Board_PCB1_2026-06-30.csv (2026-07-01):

No. | Quantity | Comment | Designator | Footprint | Value | Manufacturer Part | Manufacturer | Supplier Part | Supplier | Pin Count
1 | 20 | 22232031 | CN2,CN3,CN6,CN7,CN8,CN9,CN10,CN11,CN13,CN14,CN15,CN16,CN17,CN18,CN19,CN20,CN21,CN22,CN23,CN24 | CONN-TH_3P-P2.54_22-23-2031 |  | 22232031 | MOLEX | C234181 | LCSC | 3
2 | 1 | 22232021 | CN12 | CONN-TH_2P-P2.54_22232021 |  | 22232021 | MOLEX | C234180 | LCSC | 2
3 | 4 | Screw-Hole-M2 | SCREW1,SCREW2,SCREW3,SCREW4 | Screw-Hole-M2 |  |  |  |  |  | 1
4 | 1 | MP1584EN | U3 | MP1584EN |  |  |  |  |  | 8
5 | 1 | TB6612FNG | U4 | TB6612FNG |  |  |  |  |  | 16
6 | 1 | MODULO_INA226 | U6 | MODULO_INA226 |  |  |  |  |  | 8
7 | 1 | KF301-5.0-2P | U20 | CONN-TH_P5.00_KF301-5.0-2P |  | KF301-5.0-2P | KEFA(科发) | C474881 | LCSC | 2

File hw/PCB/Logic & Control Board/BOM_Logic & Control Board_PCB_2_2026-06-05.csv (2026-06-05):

No. | Quantity | Comment | Designator | Footprint | Value | Manufacturer Part | Manufacturer | Supplier Part | Supplier | Pin Count
1 | 6 | 22232031 | CN6,CN7,CN8,CN9,CN10,CN11 | CONN-TH_3P-P2.54_22-23-2031 |  | 22232031 | MOLEX | C234181 | LCSC | 3
2 | 1 | 22232021 | CN12 | CONN-TH_2P-P2.54_22232021 |  | 22232021 | MOLEX | C234180 | LCSC | 2
3 | 4 | Screw-Hole-M2 | SCREW1,SCREW2,SCREW3,SCREW4 | Screw-Hole-M2 |  |  |  |  |  | 1
4 | 2 | KH-6X6X5H-TJ | SW1,SW2 | 6x6x5 Tactile Switch |  | KH-6X6X5H-TJ | kinghelm(金航标) | C2837515 | LCSC | 4
5 | 15 | Test-Point | TP2,TP3,TP4,TP5,TP7,TP8,TP9,TP11,TP12,TP13,TP16,TP17,TP18,TP23,TP24 | Test-Point-0.5mm |  |  |  |  |  | 1
6 | 1 | MPU-9250 | U1 | MPU-9250 |  |  |  |  |  | 10
7 | 1 | ESP32 DEVKIT | U2 | ESP32 DEVKIT |  |  |  |  |  | 30

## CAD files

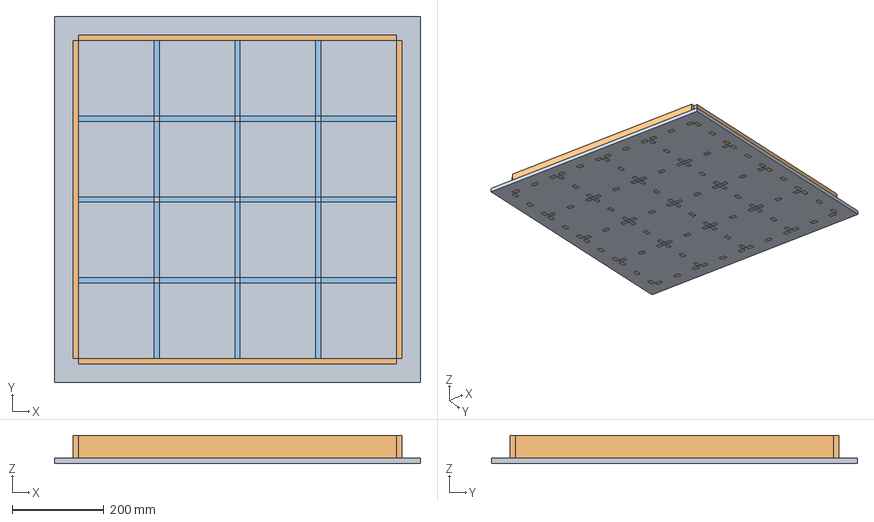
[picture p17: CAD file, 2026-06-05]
mec/Assembly/assembly_labirinto/AssemblyLabirinto1.FCStd
800.0 x 800.0 x 62.0 mm
piso
paredeexterna x 4
paredeinterna x 24

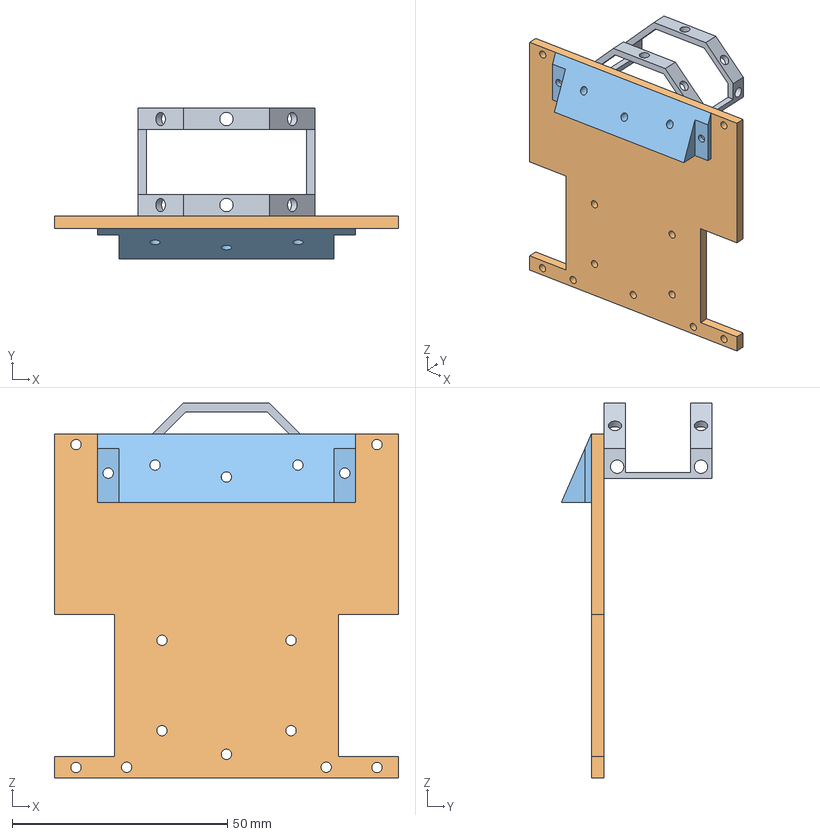
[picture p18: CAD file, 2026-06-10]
mec/Assembly/assembly_micromouse/2_0 e 2_1/Assembly-2.1.FCStd
80.0 x 35.0 x 87.2 mm
SupSensor
skid2

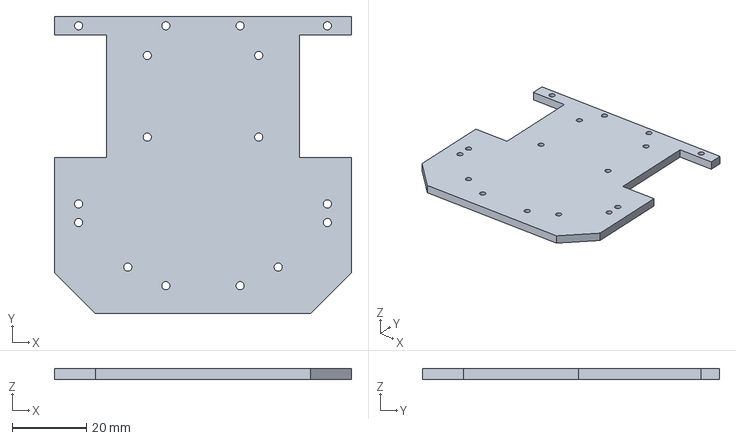
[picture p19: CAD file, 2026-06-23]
mec/Assembly/assembly_micromouse/2_2/Base3.2.FCStd
80.0 x 80.0 x 3.00 mm

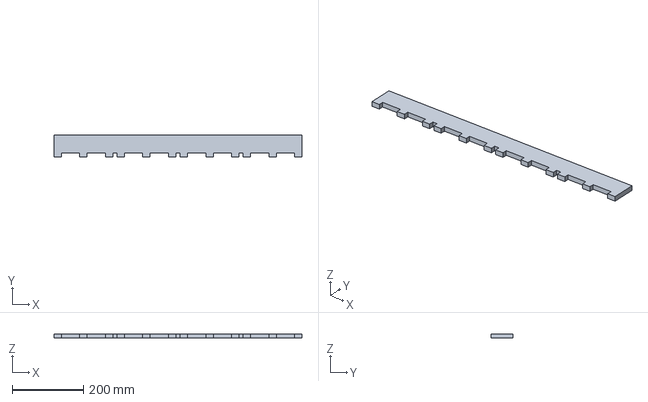
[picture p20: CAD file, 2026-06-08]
mec/desenho tecnico/labirinto/paredeexternaDraft9.FCStd
696.0 x 62.0 x 12.0 mm

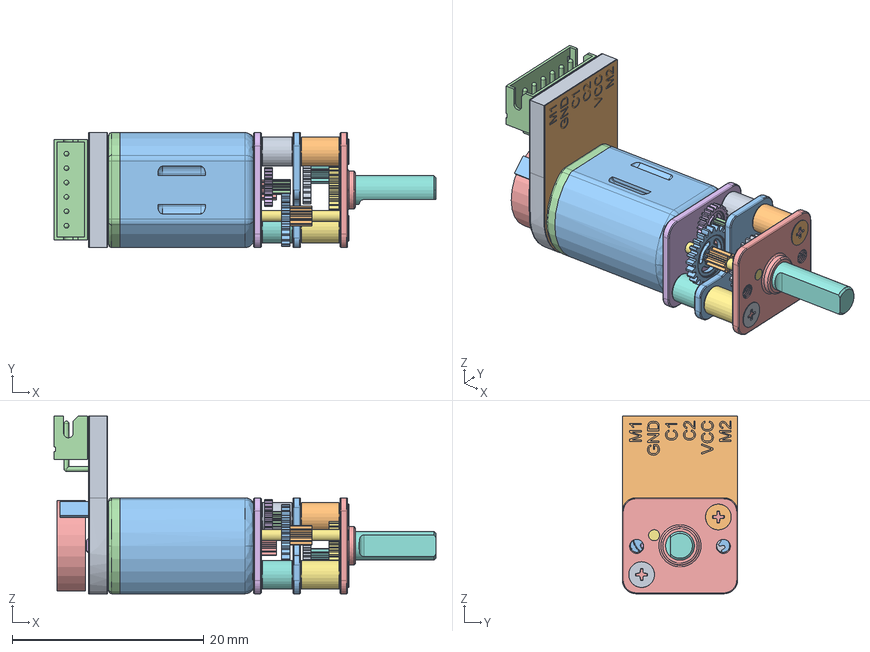
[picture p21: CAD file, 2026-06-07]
mec/modelagem 3d/blackbox/motor/motorN20_1.0.FCStd
39.8 x 12.0 x 18.5 mm
N20 Mini Micro Metall Gear Motor DC 3/6/12V v1
N20 Mini Micro Metall Gear Motor DC 3/6/12V v001
N20 Mini Micro Metall Gear Motor DC 3/6/12V v002
N20 Mini Micro Metall Gear Motor DC 3/6/12V v003
N20 Mini Micro Metall Gear Motor DC 3/6/12V v004
N20 Mini Micro Metall Gear Motor DC 3/6/12V v005
N20 Mini Micro Metall Gear Motor DC 3/6/12V v006
N20 Mini Micro Metall Gear Motor DC 3/6/12V v007
N20 Mini Micro Metall Gear Motor DC 3/6/12V v008
N20 Mini Micro Metall Gear Motor DC 3/6/12V v009
N20 Mini Micro Metall Gear Motor DC 3/6/12V v010
N20 Mini Micro Metall Gear Motor DC 3/6/12V v011
N20 Mini Micro Metall Gear Motor DC 3/6/12V v012
N20 Mini Micro Metall Gear Motor DC 3/6/12V v013
N20 Mini Micro Metall Gear Motor DC 3/6/12V v014
N20 Mini Micro Metall Gear Motor DC 3/6/12V v015
N20 Mini Micro Metall Gear Motor DC 3/6/12V v016
N20 Mini Micro Metall Gear Motor DC 3/6/12V v017
N20 Mini Micro Metall Gear Motor DC 3/6/12V v018
N20 Mini Micro Metall Gear Motor DC 3/6/12V v019
N20 Mini Micro Metall Gear Motor DC 3/6/12V v020
N20 Mini Micro Metall Gear Motor DC 3/6/12V v021
N20 Mini Micro Metall Gear Motor DC 3/6/12V v022
N20 Mini Micro Metall Gear Motor DC 3/6/12V v023
N20 Mini Micro Metall Gear Motor DC 3/6/12V v024
N20 Mini Micro Metall Gear Motor DC 3/6/12V v025
N20 Mini Micro Metall Gear Motor DC 3/6/12V v026
N20 Mini Micro Metall Gear Motor DC 3/6/12V v027
N20 Mini Micro Metall Gear Motor DC 3/6/12V v028

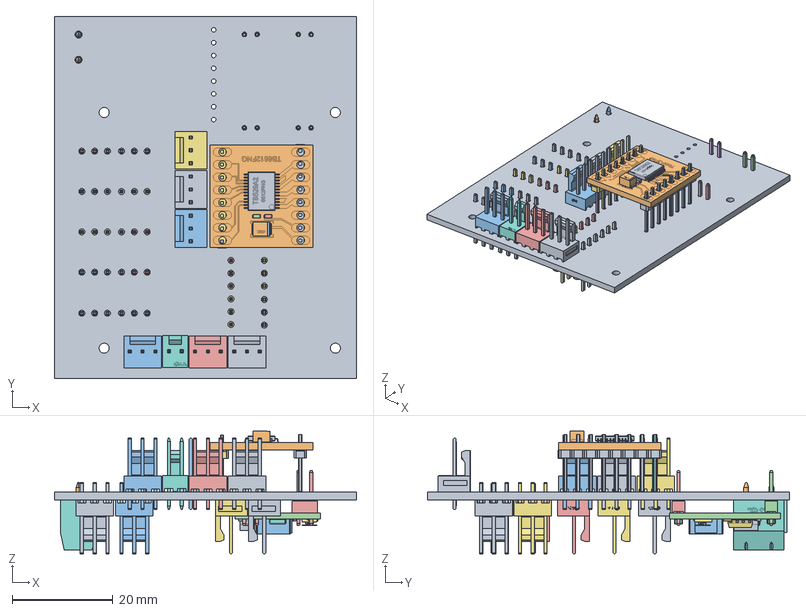
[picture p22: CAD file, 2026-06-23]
mec/modelagem 3d/blackbox/pcb_baixo/pcb_baixo_1.2.FCStd
60.0 x 71.8 x 24.3 mm
Board~EIdk
CONN-TH_P5.00_KF301-5.0-2P~CONN-TH_P5.00_KF301-5.0-2P~WNId
CONN-TH_P5.00_KF301-5.0-2P~CONN-TH_P5.00_KF301-5.0-2P~WNId001
CONN-TH_P5.00_KF301-5.0-2P~CONN-TH_P5.00_KF301-5.0-2P~WNId002
CONN-TH_P5.00_KF301-5.0-2P~CONN-TH_P5.00_KF301-5.0-2P~WNId003
CONN-TH_P5.00_KF301-5.0-2P~CONN-TH_P5.00_KF301-5.0-2P~WNId004
CONN-TH_P5.00_KF301-5.0-2P~CONN-TH_P5.00_KF301-5.0-2P~WNId005
CONN-TH_P5.00_KF301-5.0-2P~CONN-TH_P5.00_KF301-5.0-2P~WNId006
TB6612FNG~TB6612FNG~kANF
TB6612FNG~TB6612FNG~kANF001
TB6612FNG~TB6612FNG~kANF002
TB6612FNG~TB6612FNG~kANF003
TB6612FNG~TB6612FNG~kANF004
TB6612FNG~TB6612FNG~kANF005
TB6612FNG~TB6612FNG~kANF006
TB6612FNG~TB6612FNG~kANF007
TB6612FNG~TB6612FNG~kANF008
TB6612FNG~TB6612FNG~kANF009
TB6612FNG~TB6612FNG~kANF010
TB6612FNG~TB6612FNG~kANF011
TB6612FNG~TB6612FNG~kANF012
TB6612FNG~TB6612FNG~kANF013
TB6612FNG~TB6612FNG~kANF014
TB6612FNG~TB6612FNG~kANF015
TB6612FNG~TB6612FNG~kANF016
TB6612FNG~TB6612FNG~kANF017
TB6612FNG~TB6612FNG~kANF018
TB6612FNG~TB6612FNG~kANF019
TB6612FNG~TB6612FNG~kANF020
TB6612FNG~TB6612FNG~kANF021
TB6612FNG~TB6612FNG~kANF022
TB6612FNG~TB6612FNG~kANF023
TB6612FNG~TB6612FNG~kANF024
TB6612FNG~TB6612FNG~kANF026
TB6612FNG~TB6612FNG~kANF027
TB6612FNG~TB6612FNG~kANF029
TB6612FNG~TB6612FNG~kANF030
TB6612FNG~TB6612FNG~kANF031
TB6612FNG~TB6612FNG~kANF032
TB6612FNG~TB6612FNG~kANF034
TB6612FNG~TB6612FNG~kANF035
U4~TB6612FNG~TB6612FNG~jxj2
CONN-TH_3P-P2.54_22-23-2031~CONN-TH_3P-P2.54_22-23-2031~tOyN
CONN-TH_3P-P2.54_22-23-2031~CONN-TH_3P-P2.54_22-23-2031~tOyN001
CONN-TH_3P-P2.54_22-23-2031~CONN-TH_3P-P2.54_22-23-2031~tOyN002
CONN-TH_3P-P2.54_22-23-2031~CONN-TH_3P-P2.54_22-23-2031~tOyN003
CONN-TH_3P-P2.54_22-23-2031~CONN-TH_3P-P2.54_22-23-2031~tOyN004
CONN-TH_3P-P2.54_22-23-2031~CONN-TH_3P-P2.54_22-23-2031~tOyN005
CONN-TH_3P-P2.54_22-23-2031~CONN-TH_3P-P2.54_22-23-2031~tOyN006
CONN-TH_3P-P2.54_22-23-2031~CONN-TH_3P-P2.54_22-23-2031~tOyN007
CONN-TH_3P-P2.54_22-23-2031~CONN-TH_3P-P2.54_22-23-2031~tOyN008
CONN-TH_3P-P2.54_22-23-2031~CONN-TH_3P-P2.54_22-23-2031~tOyN009
CONN-TH_3P-P2.54_22-23-2031~CONN-TH_3P-P2.54_22-23-2031~tOyN010
CONN-TH_3P-P2.54_22-23-2031~CONN-TH_3P-P2.54_22-23-2031~tOyN011
CONN-TH_3P-P2.54_22-23-2031~CONN-TH_3P-P2.54_22-23-2031~tOyN012
CONN-TH_3P-P2.54_22-23-2031~CONN-TH_3P-P2.54_22-23-2031~tOyN013
CONN-TH_3P-P2.54_22-23-2031~CONN-TH_3P-P2.54_22-23-2031~tOyN015
CONN-TH_3P-P2.54_22-23-2031~CONN-TH_3P-P2.54_22-23-2031~tOyN016
CONN-TH_3P-P2.54_22-23-2031~CONN-TH_3P-P2.54_22-23-2031~tOyN017
CONN-TH_3P-P2.54_22-23-2031~CONN-TH_3P-P2.54_22-23-2031~tOyN018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

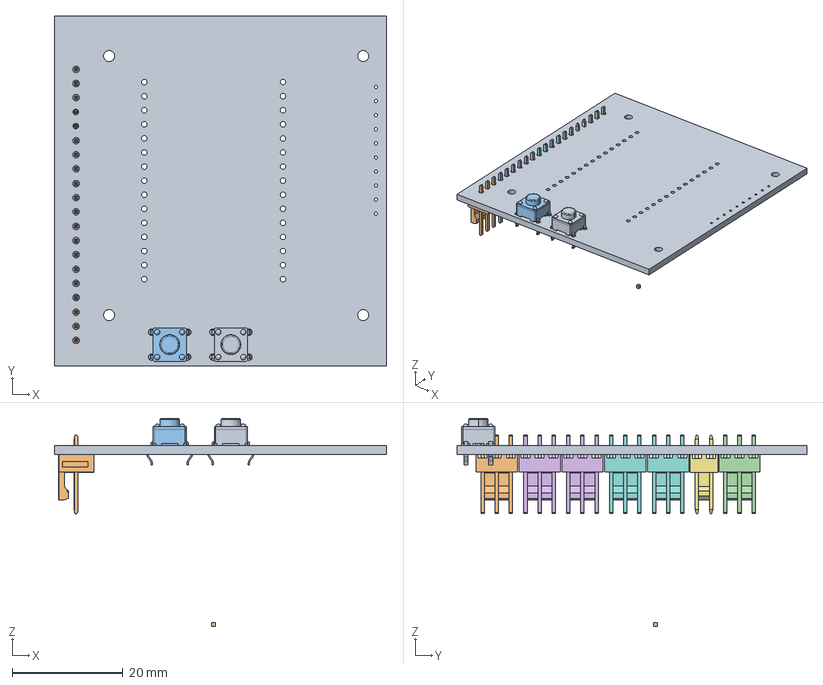
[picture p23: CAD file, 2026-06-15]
mec/modelagem 3d/blackbox/pcb_cima/pcb_cima_1.1.FCStd
60.0 x 63.1 x 37.6 mm
Board~rJGs
ESP32 DEVKIT~ESP32 DEVKIT~rJGs
6x6x5 Tactile Switch~SW-TH_4P-L6.0-W6.0-H5.0-LS6.5-P4.50~zCid
6x6x5 Tactile Switch~SW-TH_4P-L6.0-W6.0-H5.0-LS6.5-P4.50~zCid001
6x6x5 Tactile Switch~SW-TH_4P-L6.0-W6.0-H5.0-LS6.5-P4.50~zCid002
6x6x5 Tactile Switch~SW-TH_4P-L6.0-W6.0-H5.0-LS6.5-P4.50~zCid003
6x6x5 Tactile Switch~SW-TH_4P-L6.0-W6.0-H5.0-LS6.5-P4.50~zCid004
6x6x5 Tactile Switch~SW-TH_4P-L6.0-W6.0-H5.0-LS6.5-P4.50~zCid005
6x6x5 Tactile Switch~SW-TH_4P-L6.0-W6.0-H5.0-LS6.5-P4.50~zCid006
6x6x5 Tactile Switch~SW-TH_4P-L6.0-W6.0-H5.0-LS6.5-P4.50~zCid007
6x6x5 Tactile Switch~SW-TH_4P-L6.0-W6.0-H5.0-LS6.5-P4.50~zCid008
6x6x5 Tactile Switch~SW-TH_4P-L6.0-W6.0-H5.0-LS6.5-P4.50~zCid009
6x6x5 Tactile Switch~SW-TH_4P-L6.0-W6.0-H5.0-LS6.5-P4.50~zCid010
6x6x5 Tactile Switch~SW-TH_4P-L6.0-W6.0-H5.0-LS6.5-P4.50~zCid011
6x6x5 Tactile Switch~SW-TH_4P-L6.0-W6.0-H5.0-LS6.5-P4.50~zCid012
6x6x5 Tactile Switch~SW-TH_4P-L6.0-W6.0-H5.0-LS6.5-P4.50~zCid013
6x6x5 Tactile Switch~SW-TH_4P-L6.0-W6.0-H5.0-LS6.5-P4.50~zCid015
6x6x5 Tactile Switch~SW-TH_4P-L6.0-W6.0-H5.0-LS6.5-P4.50~zCid016
6x6x5 Tactile Switch~SW-TH_4P-L6.0-W6.0-H5.0-LS6.5-P4.50~zCid017
6x6x5 Tactile Switch~SW-TH_4P-L6.0-W6.0-H5.0-LS6.5-P4.50~zCid018
6x6x5 Tactile Switch~SW-TH_4P-L6.0-W6.0-H5.0-LS6.5-P4.50~zCid019
6x6x5 Tactile Switch~SW-TH_4P-L6.0-W6.0-H5.0-LS6.5-P4.50~zCid020
6x6x5 Tactile Switch~SW-TH_4P-L6.0-W6.0-H5.0-LS6.5-P4.50~zCid021
6x6x5 Tactile Switch~SW-TH_4P-L6.0-W6.0-H5.0-LS6.5-P4.50~zCid022
6x6x5 Tactile Switch~SW-TH_4P-L6.0-W6.0-H5.0-LS6.5-P4.50~zCid023
6x6x5 Tactile Switch~SW-TH_4P-L6.0-W6.0-H5.0-LS6.5-P4.50~zCid024
6x6x5 Tactile Switch~SW-TH_4P-L6.0-W6.0-H5.0-LS6.5-P4.50~zCid025
6x6x5 Tactile Switch~SW-TH_4P-L6.0-W6.0-H5.0-LS6.5-P4.50~zCid026
6x6x5 Tactile Switch~SW-TH_4P-L6.0-W6.0-H5.0-LS6.5-P4.50~zCid027
6x6x5 Tactile Switch~SW-TH_4P-L6.0-W6.0-H5.0-LS6.5-P4.50~zCid028
CONN-TH_2P-P2.54_22232021~CONN-TH_2P-P2.54_22232021~RlXC
CONN-TH_3P-P2.54_22-23-2031~CONN-TH_3P-P2.54_22-23-2031~AlsA
CONN-TH_3P-P2.54_22-23-2031~CONN-TH_3P-P2.54_22-23-2031~AlsA001
CONN-TH_3P-P2.54_22-23-2031~CONN-TH_3P-P2.54_22-23-2031~AlsA002
CONN-TH_3P-P2.54_22-23-2031~CONN-TH_3P-P2.54_22-23-2031~AlsA003
CONN-TH_3P-P2.54_22-23-2031~CONN-TH_3P-P2.54_22-23-2031~AlsA004
CONN-TH_3P-P2.54_22-23-2031~CONN-TH_3P-P2.54_22-23-2031~AlsA005
CONN-TH_3P-P2.54_22-23-2031~CONN-TH_3P-P2.54_22-23-2031~AlsA006
CONN-TH_3P-P2.54_22-23-2031~CONN-TH_3P-P2.54_22-23-2031~AlsA007
CONN-TH_3P-P2.54_22-23-2031~CONN-TH_3P-P2.54_22-23-2031~AlsA008
CONN-TH_3P-P2.54_22-23-2031~CONN-TH_3P-P2.54_22-23-2031~AlsA009
CONN-TH_3P-P2.54_22-23-2031~CONN-TH_3P-P2.54_22-23-2031~AlsA010
CONN-TH_3P-P2.54_22-23-2031~CONN-TH_3P-P2.54_22-23-2031~AlsA011
CONN-TH_3P-P2.54_22-23-2031~CONN-TH_3P-P2.54_22-23-2031~AlsA012
CONN-TH_3P-P2.54_22-23-2031~CONN-TH_3P-P2.54_22-23-2031~AlsA013
CONN-TH_3P-P2.54_22-23-2031~CONN-TH_3P-P2.54_22-23-2031~AlsA015
CONN-TH_3P-P2.54_22-23-2031~CONN-TH_3P-P2.54_22-23-2031~AlsA016
CONN-TH_3P-P2.54_22-23-2031~CONN-TH_3P-P2.54_22-23-2031~AlsA017
CONN-TH_3P-P2.54_22-23-2031~CONN-TH_3P-P2.54_22-23-2031~AlsA018
CONN-TH_3P-P2.54_22-23-2031~CONN-TH_3P-P2.54_22-23-2031~AlsA019
CONN-TH_3P-P2.54_22-23-2031~CONN-TH_3P-P2.54_22-23-2031~AlsA020
CONN-TH_3P-P2.54_22-23-2031~CONN-TH_3P-P2.54_22-23-2031~AlsA021
CONN-TH_3P-P2.54_22-23-2031~CONN-TH_3P-P2.54_22-23-2031~AlsA022
CONN-TH_3P-P2.54_22-23-2031~CONN-TH_3P-P2.54_22-23-2031~AlsA023
CONN-TH_3P-P2.54_22-23-2031~CONN-TH_3P-P2.54_22-23-2031~AlsA024
CONN-TH_3P-P2.54_22-23-2031~CONN-TH_3P-P2.54_22-23-2031~AlsA025
CONN-TH_3P-P2.54_22-23-2031~CONN-TH_3P-P2.54_22-23-2031~AlsA026
CONN-TH_3P-P2.54_22-23-2031~CONN-TH_3P-P2.54_22-23-2031~AlsA027
CONN-TH_3P-P2.54_22-23-2031~CONN-TH_3P-P2.54_22-23-2031~AlsA028
CONN-TH_3P-P2.54_22-23-2031~CONN-TH_3P-P2.54_22-23-2031~AlsA030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

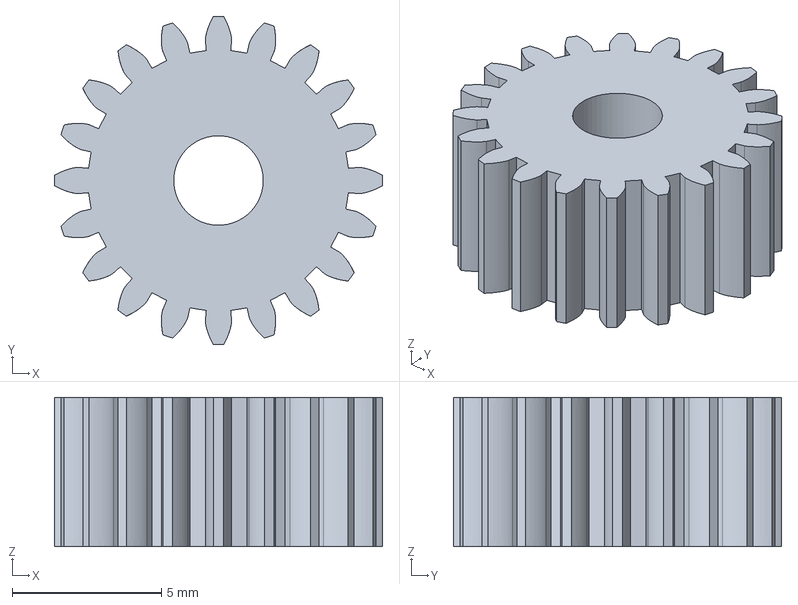
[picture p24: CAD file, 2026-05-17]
mec/modelagem 3d/engrenagem/ENGRENAGEM_MAIOR.FCStd
11.0 x 11.0 x 5.00 mm

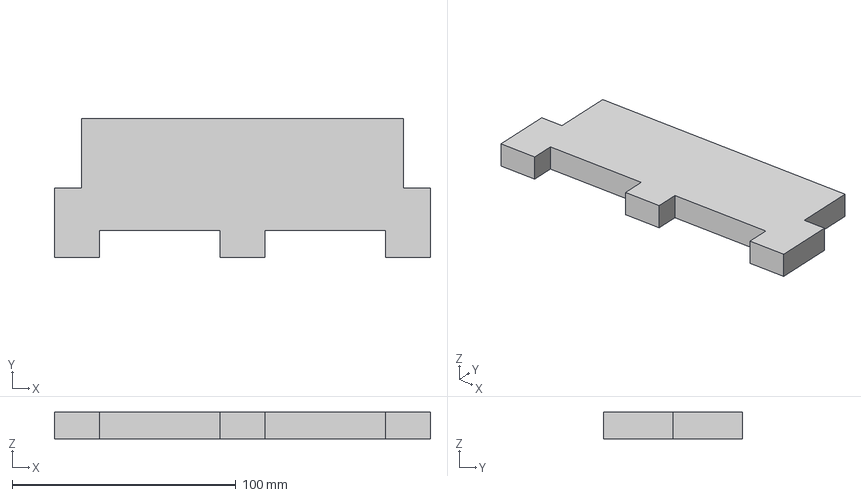
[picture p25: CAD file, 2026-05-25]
mec/modelagem 3d/labirinto/parede_interna_7.step
168.0 x 62.0 x 12.0 mm

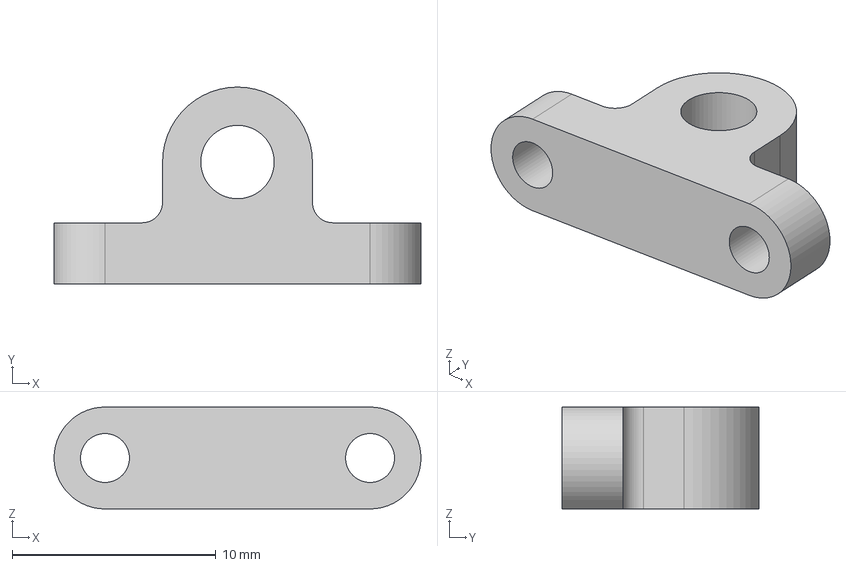
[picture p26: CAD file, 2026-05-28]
mec/modelagem 3d/mancal/mancal.step
18.0 x 9.66 x 5.00 mm

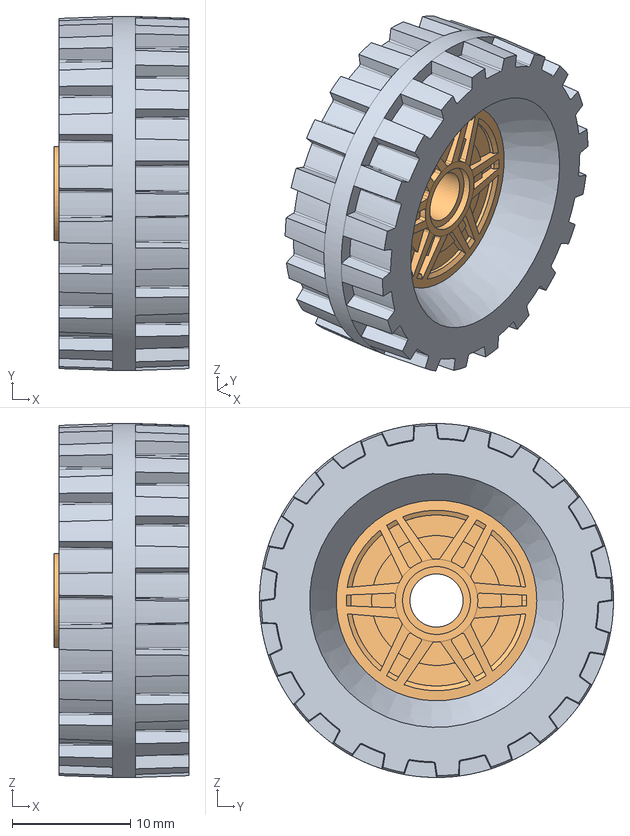
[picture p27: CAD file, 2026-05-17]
mec/modelagem 3d/roda/RodaPneu-1.0.FCStd
11.4 x 30.0 x 30.0 mm
Pneu
Roda

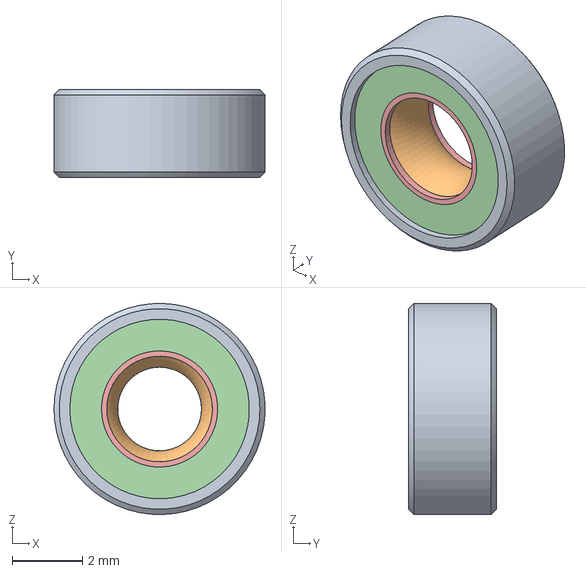
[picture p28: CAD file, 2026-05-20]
mec/modelagem 3d/rolamento/rolamento.step
6.00 x 2.50 x 6.00 mm

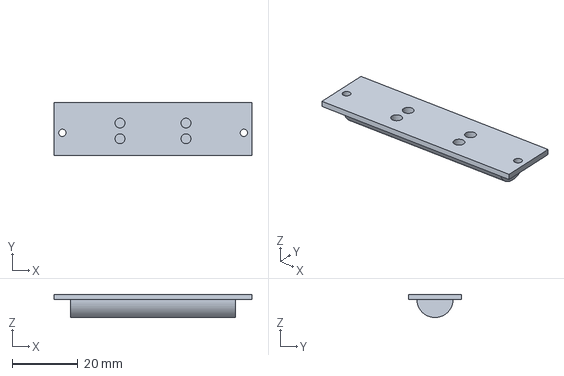
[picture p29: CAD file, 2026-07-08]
mec/modelagem 3d/skid/Skid_4.1.FCStd
60.0 x 16.0 x 7.00 mm

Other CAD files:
mec/Assembly/assembly_micromouse/2_3/Assembly-2.3.FCStd
mec/Assembly/assembly_micromouse/2_4/Assembly-2.4.FCStd
mec/Assembly/assembly_micromouse/2_2/Assembly-2.2.FCStd
mec/Assembly/assembly_micromouse/2_0 e 2_1/Assembly-2.0.FCStd
mec/modelagem 3d/base/Base3.1.FCStd
mec/Assembly/assembly_micromouse/2_0 e 2_1/Chassi_superior3.3.FCStd
mec/Assembly/assembly_micromouse/2_0 e 2_1/Roda-1.1.FCStd
mec/Assembly/assembly_micromouse/2_0 e 2_1/bateriatemp.FCStd
mec/Assembly/assembly_micromouse/2_0 e 2_1/motorN20.FCStd
mec/Assembly/assembly_micromouse/2_0 e 2_1/pcbnova.FCStd
mec/Assembly/assembly_micromouse/2_0 e 2_1/pcbsuporte.FCStd
mec/Assembly/assembly_micromouse/2_2/RodaPneu-1.1.FCStd
mec/Assembly/assembly_micromouse/2_2/Skid_3.3.FCStd
mec/Assembly/assembly_micromouse/2_2/SuporteMotor1.1.FCStd
mec/Assembly/assembly_micromouse/2_2/SuportePCB_2.2.FCStd
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

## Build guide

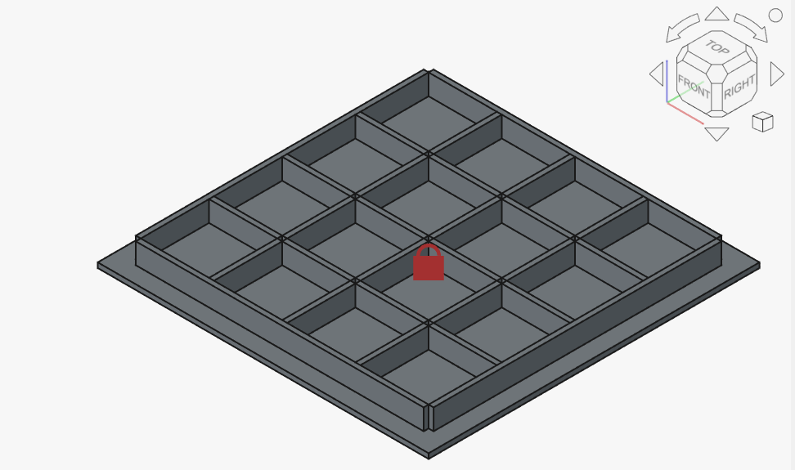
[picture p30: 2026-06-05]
mec/Assembly/assembly_labirinto/imagem-labirinto-assembly.png

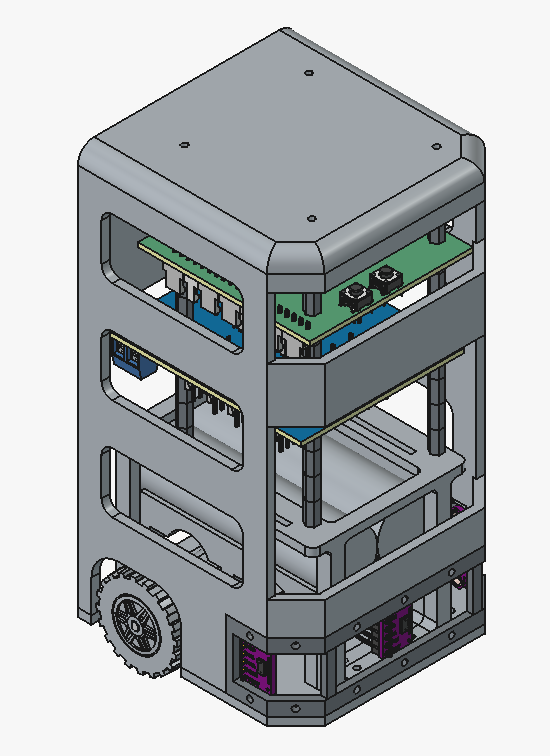
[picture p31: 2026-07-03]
mec/Assembly/assembly_micromouse/2_3/Assembly-2.3.png

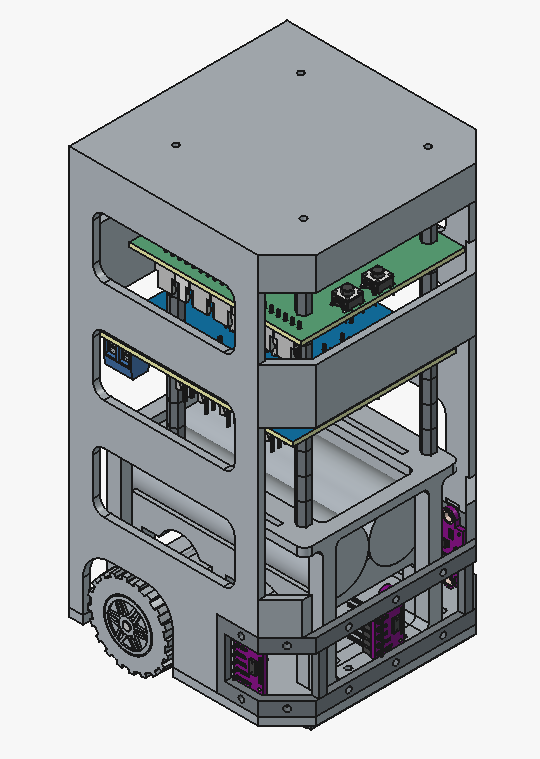
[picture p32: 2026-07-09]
mec/Assembly/assembly_micromouse/2_4/Assembly-2.4.png

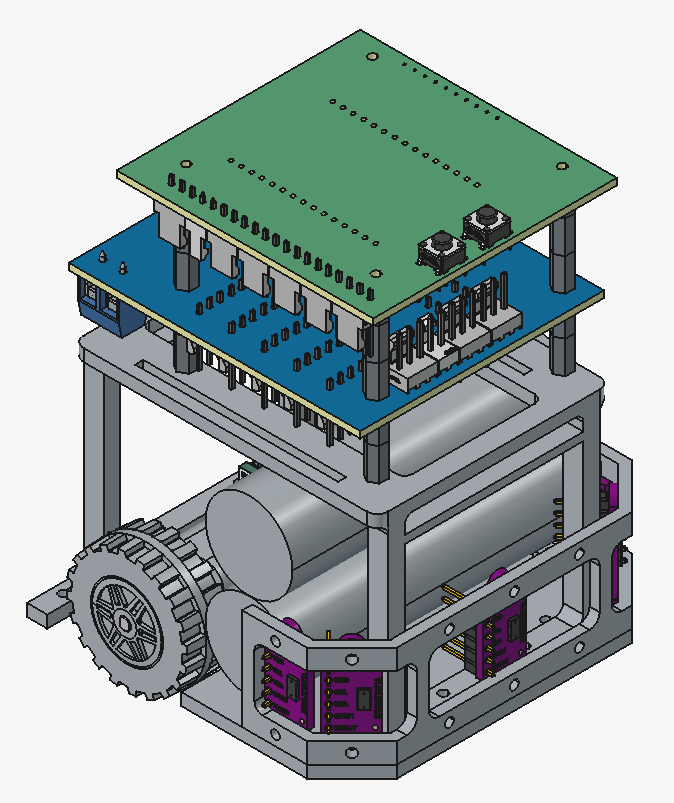
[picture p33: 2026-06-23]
mec/Assembly/assembly_micromouse/2_2/Assembly-2.2.png

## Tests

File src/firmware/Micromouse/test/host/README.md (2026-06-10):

# Testes do firmware Micromouse (host)

Suíte de testes **unitários, de integração e de sistema** que roda no PC
(Windows), sem precisar do ESP32, do QEMU nem do ambiente ESP-IDF. Os arquivos
`.cpp` reais do firmware são compilados com o MSVC (`cl.exe`) contra *mocks* das
APIs do ESP-IDF.

## Como rodar

```powershell
# a partir desta pasta (test/host)
.\run_tests.ps1

# apenas um alvo
.\run_tests.ps1 maze
```

O script localiza o `vcvars64.bat` (Visual Studio Build Tools), importa o
ambiente do compilador, compila cada alvo em `build/` e executa. Sai com código
0 se tudo passar, 1 se algo falhar.

> Requisito: Visual Studio Build Tools 2022 (ou Community) com o componente
> "Desenvolvimento para desktop com C++". O `cJSON.c` usado pelos testes vem de
> `managed_components/espressif__cjson/`.

## O que é coberto

| Alvo | Módulo testado | Tipo | Resumo |
|---|---|---|---|
| `test_maze` | `main/maze` | unitário + **integração** | Geometria, registro de paredes (simetria), flood fill (Manhattan, respeito a paredes, células inalcançáveis), gradiente, rota ótima e o **ciclo completo da máquina de estados** (Explorar → Refinar → Retornar → FastRun) em labirintos abertos, com paredes e com objetivo bloqueado. |
| `test_envio_dados` | `main/envio_dados` | unitário | Cada pacote JSON (tipos 0–5) é serializado e re-parseado com cJSON para conferir os campos; propagação de erro e rejeição de URL nula. |
| `test_battery` | `main/battery` | unitário | `voltageToSOC` (extremos e saturação), contagem de Coulomb, correção por tensão em repouso, saturação 0–100 % e o filtro de média móvel + LPF. |
| `test_motor` | `main/motor` | unitário | Lógica da ponte H (sentido para frente/ré/freio), saturação do duty em 1023, liberação do standby e leitura do encoder (PCNT). |
| `test_telemetria` | `main/telemetria` | unitário + integração | *Gating* por Wi-Fi, timestamp relativo ao início, e o *heartbeat* de inatividade (limiar, reset por atividade, supressão sem Wi-Fi). |
| `test_system` | `battery` + `maze` + `telemetria` + `envio_dados` | **sistema (E2E)** | Cadeia completa com os módulos **reais** ligados entre si (só Wi-Fi/HTTP/relógio/INA226 mockados): uma missão do robô gera o fluxo de telemetria que um *backend simulado* faz o *parse* a partir do JSON que cruzou a rede. Cobre missão completa (config→movimentos→rota→fim, timestamps monotônicos, descarga da bateria), fidelidade das paredes reportadas (sem fantasmas), gating por queda/reconexão de Wi-Fi, propagação e recuperação de falha de rede, *heartbeat* carregando o SOC atual, e alerta de temperatura no meio da corrida. |

Total atual: **54 testes / 230 verificações**.

## Pirâmide de testes

- **Unitário** — um módulo isolado contra mocks (`test_battery`, `test_motor`,
  `test_envio_dados`, partes de `test_maze`/`test_telemetria`).
- **Integração** — a máquina de estados do labirinto de ponta a ponta, ou a
  telemetria sobre um `envio_dados` mockado (`test_maze`, `test_telemetria`).
- **Sistema (E2E)** — os módulos **reais** do firmware compilados juntos, com
  apenas as bordas de hardware/rede mockadas, validando o comportamento
  observável no JSON que sai pela rede (`test_system`).

## Estrutura

```
test/host/
  framework.hpp          Framework minimalista (TEST_CASE / CHECK* / REQUIRE)
  run_tests.ps1          Compila e roda todos os alvos com o MSVC
  test_*.cpp             Um arquivo de teste por módulo
  mocks/                 Mocks das APIs do ESP-IDF / drivers / bibliotecas
    esp_err.h  esp_log.h  esp_timer.h(+.cpp)
    esp_http_client.h(+_mock.cpp)
    driver/gpio.h ledc.h pulse_cnt.h i2c_types.h  (+ driver_mock.cpp)
    ina226.hpp(+_mock.cpp)   i2c_manager_mock.cpp
    wifi.hpp(+_mock.cpp)     mock_envio_dados.h(+.cpp)
  build/                 Artefatos de compilação (ignorado pelo git)
```

Os mocks expõem ajudantes (`mock_*`) para os testes injetarem leituras de
sensores, avançarem o relógio virtual, controlarem o estado do Wi-Fi e
inspecionarem o que foi "enviado".

## Escrevendo um novo teste

```cpp
#include "framework.hpp"

TEST_CASE(meu_caso) {
    CHECK(1 + 1 == 2);
    CHECK_EQ(soma(2, 3), 5);
    CHECK_FLOAT_EQ(media, 7.5, 1e-3);
    REQUIRE(ptr != nullptr);   // aborta o caso se falhar
}

TEST_MAIN()  // uma vez por executável
```

Para um módulo novo, adicione um bloco em `$targets` no `run_tests.ps1` listando
os `.cpp` e os diretórios de include.

## Módulos não cobertos aqui (e por quê)

`imu`, `vl53l0x`, `wifi`, `sd_card` e `i2c_manager` são essencialmente *cola* de
hardware: quase toda a lógica é chamada direta de drivers I2C/SPI/GPIO ou de
bibliotecas externas (MPU9250, VL53L0X, esp_wifi). Não há algoritmo isolável que
um teste de host validaria de forma significativa — eles exigem **teste no alvo
(on-target / HIL)** com o sensor real ou em QEMU. Para isso, o caminho indicado é
o framework Unity do próprio ESP-IDF (`idf.py create-component`/`pytest-embedded`)
executado no ESP32.

## Notas

- Os mocks reproduzem só a superfície de API que cada módulo usa; ao mexer no
  firmware, pode ser preciso ampliar um mock.
- O relógio dos testes é virtual (`mock_timer_*`), então os testes de tempo são
  determinísticos e instantâneos.

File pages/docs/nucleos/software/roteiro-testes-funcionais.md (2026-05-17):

# Roteiro de Testes Funcionais - Software

Este documento define os **casos de teste funcionais** do software do Micromouse, com base nos requisitos e histórias de usuário. Os testes validam as funcionalidades críticas do software, desde a recepção de dados até a visualização e persistência de resultados.

---

### CT-S01 - Recepção de dados do Micromouse

| Parâmetro | Detalhe |
| :--- | :--- |
| **Código do caso de teste** | CT-S01 |
| **Nome do caso de teste** | Recepção de telemetria |
| **Objetivo do caso de teste** | Verificar se o sistema recebe os dados de telemetria do Micromouse com sucesso. |
| **Pré-condições do sistema para o teste ser realizado, quando se aplicar** | Micromouse ligado, conectado à rede e sistema web rodando e aberto. |
| **Descrição dos procedimentos a serem executados para o teste** | 1. Iniciar conexão do sistema com o Micromouse<br>2. Monitorar a porta de recebimento dos dados<br>3. Registrar o comportamento |
| **Resultado esperado para o teste ser aprovado (pós-condição após realizado o teste)** | Dados de telemetria recebidos continuamente, sem falhas ou perda de pacotes. |

### CT-S02 - Validação da telemetria recebida

| Parâmetro | Detalhe |
| :--- | :--- |
| **Código do caso de teste** | CT-S02 |
| **Nome do caso de teste** | Validação de pacotes de dados |
| **Objetivo do caso de teste** | Garantir que o sistema valida corretamente os pacotes recebidos, rejeitando formatos inválidos. |
| **Pré-condições do sistema para o teste ser realizado, quando se aplicar** | Conexão estabelecida entre o sistema e o Micromouse. |
| **Descrição dos procedimentos a serem executados para o teste** | 1. Injetar dados de telemetria (válidos e corrompidos/inválidos)<br>2. Observar o log de processamento do backend<br>3. Registrar o comportamento |
| **Resultado esperado para o teste ser aprovado (pós-condição após realizado o teste)** | O sistema aceita pacotes válidos para processamento e descarta/alerta sobre pacotes inválidos. |

### CT-S03 - Monitoramento em tempo real

| Parâmetro | Detalhe |
| :--- | :--- |
| **Código do caso de teste** | CT-S03 |
| **Nome do caso de teste** | Monitoramento da corrida em tempo real |
| **Objetivo do caso de teste** | Avaliar se a interface web atualiza o estado do Micromouse no labirinto instantaneamente. |
| **Pré-condições do sistema para o teste ser realizado, quando se aplicar** | Sistema recebendo dados válidos de telemetria e dashboard aberto. |
| **Descrição dos procedimentos a serem executados para o teste** | 1. Acessar a tela de monitoramento no app<br>2. Observar a atualização visual da posição e dos sensores<br>3. Registrar o comportamento |
| **Resultado esperado para o teste ser aprovado (pós-condição após realizado o teste)** | A interface gráfica exibe a movimentação do rato no labirinto instantaneamente, sem lag perceptível. |

### CT-S04 - Exibição dos indicadores da corrida

| Parâmetro | Detalhe |
| :--- | :--- |
| **Código do caso de teste** | CT-S04 |
| **Nome do caso de teste** | Exibição de indicadores da corrida |
| **Objetivo do caso de teste** | Confirmar a correta exibição dos indicadores como tempo decorrido, velocidade e status. |
| **Pré-condições do sistema para o teste ser realizado, quando se aplicar** | Micromouse em corrida ativa, comunicando com o sistema. |
| **Descrição dos procedimentos a serem executados para o teste** | 1. Acessar o painel da corrida<br>2. Verificar os valores numéricos e gráficos exibidos<br>3. Registrar o comportamento |
| **Resultado esperado para o teste ser aprovado (pós-condição após realizado o teste)** | Os indicadores refletem os dados exatos do rato em tempo real e de forma legível. |

### CT-S05 - Persistência dos dados finais

| Parâmetro | Detalhe |
| :--- | :--- |
| **Código do caso de teste** | CT-S05 |
| **Nome do caso de teste** | Persistência de corrida finalizada |
| **Objetivo do caso de teste** | Assegurar que os dados totais da corrida e o mapa descoberto são salvos no banco de dados. |
| **Pré-condições do sistema para o teste ser realizado, quando se aplicar** | O percurso do Micromouse foi concluído com sucesso. |
| **Descrição dos procedimentos a serem executados para o teste** | 1. Acionar a conclusão da corrida (via Micromouse ou interface)<br>2. Consultar o banco de dados do sistema<br>3. Registrar o comportamento |
| **Resultado esperado para o teste ser aprovado (pós-condição após realizado o teste)** | Os registros completos da corrida (tempo total, mapa, rota executada) são persistidos. |

### CT-S06 - Consulta por labirinto

| Parâmetro | Detalhe |
| :--- | :--- |
| **Código do caso de teste** | CT-S06 |
| **Nome do caso de teste** | Consulta de resultados por labirinto |
| **Objetivo do caso de teste** | Verificar se é possível filtrar os históricos de corrida para visualizar os dados de um labirinto específico. |
| **Pré-condições do sistema para o teste ser realizado, quando se aplicar** | Existência de dados de corridas persistidos associados a diferentes labirintos. |
| **Descrição dos procedimentos a serem executados para o teste** | 1. Acessar a página de histórico/resultados<br>2. Selecionar e aplicar o filtro por um labirinto alvo<br>3. Registrar o comportamento |
| **Resultado esperado para o teste ser aprovado (pós-condição após realizado o teste)** | O sistema atualiza a listagem exibindo somente as corridas pertencentes ao labirinto pesquisado. |

### CT-S07 - Consulta geral de resultados

| Parâmetro | Detalhe |
| :--- | :--- |
| **Código do caso de teste** | CT-S07 |
| **Nome do caso de teste** | Consulta geral do histórico |
| **Objetivo do caso de teste** | Validar a exibição e a funcionalidade de listagem de todo o histórico de resultados globais. |
| **Pré-condições do sistema para o teste ser realizado, quando se aplicar** | Banco de dados populado com diversas corridas salvas. |
| **Descrição dos procedimentos a serem executados para o teste** | 1. Acessar a tela geral de resultados<br>2. Navegar pela listagem de informações<br>3. Registrar o comportamento |
| **Resultado esperado para o teste ser aprovado (pós-condição após realizado o teste)** | O sistema exibe o histórico integral corretamente, com as informações principais formatadas e precisas. |

### CT-SE01 - Inicialização do barramento I2C

| Parâmetro | Detalhe |
| :--- | :--- |
| **Código do caso de teste** | CT-SE01 |
| **Nome do caso de teste** | Inicialização do barramento I2C compartilhado |
| **Objetivo do caso de teste** | Verificar se o firmware inicializa corretamente o barramento I2C usado pelos sensores do Micromouse. |
| **Pré-condições do sistema para o teste ser realizado, quando se aplicar** | Firmware embarcado compilado e placas/sensores conectados corretamente. |
| **Descrição dos procedimentos a serem executados para o teste** | 1. Ligar o Micromouse<br>2. Observar os logs de inicialização do firmware<br>3. Confirmar a criação do barramento I2C compartilhado<br>4. Registrar o comportamento |
| **Resultado esperado para o teste ser aprovado (pós-condição após realizado o teste)** | O barramento I2C é inicializado com sucesso e fica disponível para os módulos dependentes. |

### CT-SE02 - Leitura da bateria

| Parâmetro | Detalhe |
| :--- | :--- |
| **Código do caso de teste** | CT-SE02 |
| **Nome do caso de teste** | Monitoramento e filtragem da bateria |
| **Objetivo do caso de teste** | Garantir que o módulo de bateria leia tensão, corrente, potência e SOC corretamente. |
| **Pré-condições do sistema para o teste ser realizado, quando se aplicar** | Sensor INA226 funcionando e firmware com o módulo de bateria ativo. |
| **Descrição dos procedimentos a serem executados para o teste** | 1. Energizar o Micromouse<br>2. Acompanhar as leituras geradas pelo módulo de bateria<br>3. Verificar se os valores variam de forma coerente com a alimentação<br>4. Registrar o comportamento |
| **Resultado esperado para o teste ser aprovado (pós-condição após realizado o teste)** | O sistema exibe leituras válidas e filtradas de tensão, corrente, potência e SOC. |

### CT-SE03 - Leitura da IMU

| Parâmetro | Detalhe |
| :--- | :--- |
| **Código do caso de teste** | CT-SE03 |
| **Nome do caso de teste** | Atualização dos dados da IMU |
| **Objetivo do caso de teste** | Verificar se o módulo de IMU atualiza corretamente aceleração, giroscópio e temperatura. |
| **Pré-condições do sistema para o teste ser realizado, quando se aplicar** | Sensor MPU-9250 conectado e firmware com a tarefa de IMU em execução. |
| **Descrição dos procedimentos a serem executados para o teste** | 1. Iniciar o Micromouse<br>2. Observar os logs do módulo de IMU<br>3. Movimentar manualmente a placa para gerar variações nos eixos<br>4. Registrar o comportamento |
| **Resultado esperado para o teste ser aprovado (pós-condição após realizado o teste)** | O firmware lê e atualiza os dados da IMU sem falhas, refletindo mudanças de movimento em tempo real. |

### CT-SE04 - Controle dos motores

| Parâmetro | Detalhe |
| :--- | :--- |
| **Código do caso de teste** | CT-SE04 |
| **Nome do caso de teste** | Controle dos motores e encoders |
| **Objetivo do caso de teste** | Confirmar que o módulo de motor aplica PWM corretamente e contabiliza os pulsos dos encoders. |
| **Pré-condições do sistema para o teste ser realizado, quando se aplicar** | Motores e encoders conectados ao firmware embarcado. |
| **Descrição dos procedimentos a serem executados para o teste** | 1. Ligar o sistema embarcado<br>2. Aplicar comandos de movimentação aos motores<br>3. Observar a resposta física dos motores<br>4. Validar a contagem dos encoders<br>5. Registrar o comportamento |
| **Resultado esperado para o teste ser aprovado (pós-condição após realizado o teste)** | Os motores respondem aos comandos e os encoders contabilizam movimento de forma consistente. |

### CT-SE05 - Leitura do sensor TOF

| Parâmetro | Detalhe |
| :--- | :--- |
| **Código do caso de teste** | CT-SE05 |
| **Nome do caso de teste** | Leitura de distância do sensor VL53L0X |
| **Objetivo do caso de teste** | Verificar se o sensor de distância retorna medidas estáveis e compatíveis com o ambiente. |
| **Pré-condições do sistema para o teste ser realizado, quando se aplicar** | Sensor VL53L0X instalado e operacional, com linha de visão desobstruída. |
| **Descrição dos procedimentos a serem executados para o teste** | 1. Iniciar o firmware<br>2. Observar as leituras de distância do sensor TOF<br>3. Aproximar e afastar um obstáculo<br>4. Registrar o comportamento |
| **Resultado esperado para o teste ser aprovado (pós-condição após realizado o teste)** | As leituras de distância são atualizadas corretamente e acompanham a variação do obstáculo. |

### CT-SE06 - Persistência em cartão SD

| Parâmetro | Detalhe |
| :--- | :--- |
| **Código do caso de teste** | CT-SE06 |
| **Nome do caso de teste** | Gravação de telemetria no cartão SD |
| **Objetivo do caso de teste** | Garantir que o módulo de cartão SD registre os dados de telemetria em arquivo com sucesso. |
| **Pré-condições do sistema para o teste ser realizado, quando se aplicar** | Cartão SD inserido e montado corretamente no sistema. |
| **Descrição dos procedimentos a serem executados para o teste** | 1. Iniciar o firmware com o cartão SD presente<br>2. Gerar telemetria dos sensores e do sistema<br>3. Verificar a criação ou atualização do arquivo CSV<br>4. Registrar o comportamento |
| **Resultado esperado para o teste ser aprovado (pós-condição após realizado o teste)** | Os dados são gravados no arquivo configurado no cartão SD sem perda de registros. |

### CT-SE07 - Integração do firmware principal

| Parâmetro | Detalhe |
| :--- | :--- |
| **Código do caso de teste** | CT-SE07 |
| **Nome do caso de teste** | Integração geral dos módulos embarcados |
| **Objetivo do caso de teste** | Validar se o firmware principal inicializa e coordena corretamente todos os módulos embarcados. |
| **Pré-condições do sistema para o teste ser realizado, quando se aplicar** | Todos os sensores e atuadores montados conforme o hardware do Micromouse. |
| **Descrição dos procedimentos a serem executados para o teste** | 1. Ligar o Micromouse<br>2. Verificar a inicialização conjunta de bateria, IMU, motor, TOF e SD card<br>3. Observar a troca de dados entre as tarefas do firmware<br>4. Registrar o comportamento |
| **Resultado esperado para o teste ser aprovado (pós-condição após realizado o teste)** | O firmware sobe todos os módulos sem travamentos e mantém a operação integrada de forma estável. |

### CT-SE08 - Algoritmo de exploração cega (Frontier Based) até a chegada

| Parâmetro | Detalhe |
| :--- | :--- |
| **Código do caso de teste** | CT-SE08 |
| **Nome do caso de teste** | Exploração Frontier Based até localizar a célula de chegada |
| **Objetivo do caso de teste** | Validar que o Frontier Based explora o labirinto de forma eficiente até encontrar a célula objetivo. |
| **Pré-condições do sistema para o teste ser realizado, quando se aplicar** | Algoritmo Frontier Based implementado no firmware, sensores TOF operacionais, Micromouse no ponto de partida. |
| **Descrição dos procedimentos a serem executados para o teste** | 1. Iniciar o Micromouse no ponto de partida do labirinto<br>2. Ativar o modo de exploração Frontier Based<br>3. Monitorar movimento e exploração das fronteiras do labirinto<br>4. Registrar células visitadas, mapa parcial construído e tempo até localizar chegada<br>5. Validar que o algoritmo detecta a célula de chegada e encerra exploração |
| **Resultado esperado para o teste ser aprovado (pós-condição após realizado o teste)** | O Micromouse localiza e alcança a célula de chegada, explorando sistematicamente sem entrar em loops infinitos. Mapa parcial é construído com precisão. |

### CT-SE09 - Transição para FloodFill após localizar chegada

| Parâmetro | Detalhe |
| :--- | :--- |
| **Código do caso de teste** | CT-SE09 |
| **Nome do caso de teste** | Mudança de Frontier Based para FloodFill na chegada |
| **Objetivo do caso de teste** | Validar que o firmware alterna automaticamente para FloodFill ao detectar a célula de chegada e mapeia o restante do labirinto. |
| **Pré-condições do sistema para o teste ser realizado, quando se aplicar** | CT-SE08 concluído (chegada localizada), mapa parcial armazenado em memória. |
| **Descrição dos procedimentos a serem executados para o teste** | 1. Com Micromouse na célula de chegada, ativar algoritmo de mapeamento completo<br>2. Executar FloodFill a partir da célula de chegada<br>3. Registrar propagação de distâncias para todas as células alcançáveis<br>4. Validar que o mapa é atualizado com paredes não exploradas previamente<br>5. Confirmar que a transição ocorre sem perda de dados do mapa anterior |
| **Resultado esperado para o teste ser aprovado (pós-condição após realizado o teste)** | FloodFill mapeia todas as células alcançáveis com distâncias corretas a partir da chegada, preservando informações do Frontier Based e preparando para cálculo da rota ótima. |

### CT-SE10 - Navegação ótima após mapeamento completo

| Parâmetro | Detalhe |
| :--- | :--- |
| **Código do caso de teste** | CT-SE10 |
| **Nome do caso de teste** | Navegação pelo caminho ótimo calculado |
| **Objetivo do caso de teste** | Validar que o Micromouse navega pelo caminho ótimo (menor distância) do ponto de partida até a chegada. |
| **Pré-condições do sistema para o teste ser realizado, quando se aplicar** | CT-SE09 concluído (mapa completo e distâncias calculadas pelo FloodFill). |
| **Descrição dos procedimentos a serem executados para o teste** | 1. Retornar o Micromouse ao ponto de partida<br>2. Ativar modo de navegação ótima<br>3. Monitorar caminho percorrido e validar que segue as menores distâncias<br>4. Registrar tempo total de execução e número de células percorridas<br>5. Comparar com a distância teórica do mapa FloodFill |
| **Resultado esperado para o teste ser aprovado (pós-condição após realizado o teste)** | Micromouse segue o caminho ótimo sem desvios, alcançando a chegada no tempo mínimo teórico, com margem de erro apenas para movimentos físicos e alinhamento. |

### CT-SE11 - Envio de batch de dados via HTTP

| Parâmetro | Detalhe |
| :--- | :--- |
| **Código do caso de teste** | CT-SE11 |
| **Nome do caso de teste** | Envio de batch de telemetria ao servidor backend |
| **Objetivo do caso de teste** | Validar que o firmware coleta dados de telemetria e os envia em lotes via HTTP para o backend. |
| **Pré-condições do sistema para o teste ser realizado, quando se aplicar** | Micromouse com conectividade de rede (WiFi), backend rodando e acessível, fim de execução ou intervalo de envio atingido. |
| **Descrição dos procedimentos a serem executados para o teste** | 1. Registrar telemetria durante execução (posição, sensores, bateria, etc)<br>2. Aguardar conclusão de batch (após N registros ou fim de corrida)<br>3. Monitorar formação e serialização dos dados em JSON<br>4. Enviar POST HTTP com batch de dados ao servidor<br>5. Validar resposta HTTP (status 200, confirmação de recebimento)<br>6. Verificar se dados chegaram íntegros no backend |
| **Resultado esperado para o teste ser aprovado (pós-condição após realizado o teste)** | Batch é enviado com sucesso via HTTP, servidor responde com confirmação, e todos os registros de telemetria são persistidos sem perda ou corrupção. |

### CT-HW01 - Sistema de energia

| Parâmetro | Detalhe |
| :--- | :--- |
| **Código do caso de teste** | CT-HW01 |
| **Nome do caso de teste** | Funcionamento do regulador de tensão |
| **Objetivo do caso de teste** | Verificar se o regulador MP1584EN fornece 3.3V estável na saída. |
| **Pré-condições do sistema para o teste ser realizado, quando se aplicar** | Placa de PCB montada, bateria conectada (12V nominal), multímetro calibrado. |
| **Descrição dos procedimentos a serem executados para o teste** | 1. Conectar bateria ao conector CN3 (BATERIA)<br>2. Medir tensão de saída do regulador (pinos VCC)<br>3. Variar carga conectando/desconectando módulos<br>4. Registrar variações de tensão |
| **Resultado esperado para o teste ser aprovado (pós-condição após realizado o teste)** | Tensão de saída = 3.3V ±5% em regime permanente, ripple < 100mV em transiente. |

### CT-HW02 - Subsistema de gestão energética (INA226)

| Parâmetro | Detalhe |
| :--- | :--- |
| **Código do caso de teste** | CT-HW02 |
| **Nome do caso de teste** | Leitura correta de tensão, corrente e potência da bateria |
| **Objetivo do caso de teste** | Validar que o sensor INA226 mede com precisão as métricas de consumo de energia. |
| **Pré-condições do sistema para o teste ser realizado, quando se aplicar** | Sensor INA226 soldado no módulo, conectado ao barramento I2C, bateria conectada. |
| **Descrição dos procedimentos a serem executados para o teste** | 1. Ligar o ESP32 e ler valores do INA226 via barramento I2C<br>2. Medir tensão com multímetro e comparar com leitura do INA226<br>3. Aplicar diferentes cargas aos motores<br>4. Verificar variação de corrente e potência |
| **Resultado esperado para o teste ser aprovado (pós-condição após realizado o teste)** | Leituras do INA226 coincidem com multímetro (±2%), e responde adequadamente a variações de carga. |

### CT-HW03 - Subsistema de navegação inercial (MPU-9250)

| Parâmetro | Detalhe |
| :--- | :--- |
| **Código do caso de teste** | CT-HW03 |
| **Nome do caso de teste** | Comunicação I2C e leitura do MPU-9250 |
| **Objetivo do caso de teste** | Garantir que o sensor MPU-9250 comunica corretamente via I2C e retorna dados válidos. |
| **Pré-condições do sistema para o teste ser realizado, quando se aplicar** | Sensor MPU-9250 soldado na placa, alimentação em 3.3V, barramento I2C operacional. |
| **Descrição dos procedimentos a serem executados para o teste** | 1. Energizar a placa<br>2. Verificar presença do dispositivo no barramento I2C (endereço 0x68)<br>3. Ler registros de aceleração, giroscópio e temperatura<br>4. Movimentar a placa e verificar mudanças nos eixos XYZ |
| **Resultado esperado para o teste ser aprovado (pós-condição após realizado o teste)** | Comunicação I2C estabelecida, dados de aceleração/giroscópio coerentes com movimento físico. |

### CT-HW04 - Subsistema infravermelho (VL53L0X)

| Parâmetro | Detalhe |
| :--- | :--- |
| **Código do caso de teste** | CT-HW04 |
| **Nome do caso de teste** | Funcionamento dos sensores de distância VL53L0X |
| **Objetivo do caso de teste** | Validar que cada sensor VL53L0X (CN4, CN5 com XSHUT controle) retorna leituras de distância confiáveis. |
| **Pré-condições do sistema para o teste ser realizado, quando se aplicar** | Sensores VL53L0X instalados nos conectores CN4 e CN5, barramento I2C operacional, ESP32 ligado. |
| **Descrição dos procedimentos a serem executados para o teste** | 1. Energizar o sistema<br>2. Ativar cada sensor via pino XSHUT<br>3. Ler valores de distância para obstáculos a 10cm, 20cm e 30cm<br>4. Registrar precisão e tempo de resposta |
| **Resultado esperado para o teste ser aprovado (pós-condição após realizado o teste)** | Ambos os sensores retornam leituras dentro de ±10% do valor real, com resposta < 100ms. |

### CT-HW05 - Subsistema de motores (TB6612FNG)

| Parâmetro | Detalhe |
| :--- | :--- |
| **Código do caso de teste** | CT-HW05 |
| **Nome do caso de teste** | Controle de motores via ponte H TB6612FNG |
| **Objetivo do caso de teste** | Confirmar que a ponte H comuta corretamente e os motores executam movimentos em ambas as direções. |
| **Pré-condições do sistema para o teste ser realizado, quando se aplicar** | TB6612FNG soldado, motores conectados em M1 e M2, encoders instalados, ESP32 ligado. |
| **Descrição dos procedimentos a serem executados para o teste** | 1. Aplicar PWM a AI1/PWMA (motor esquerdo) com variação de duty cycle (0%-100%)<br>2. Aplicar PWM a BI1/PWMB (motor direito) com variação de duty cycle<br>3. Testar sentidos de rotação (AI2, BI2 controlam direção)<br>4. Validar leitura dos encoders para cada movimento |
| **Resultado esperado para o teste ser aprovado (pós-condição após realizado o teste)** | Motores respondem aos comandos PWM, giram em ambas as direções e encoders contabilizam pulsos consistentemente. |

### CT-HW06 - Subsistema de microSD

| Parâmetro | Detalhe |
| :--- | :--- |
| **Código do caso de teste** | CT-HW06 |
| **Nome do caso de teste** | Comunicação SPI e funcionamento do cartão SD |
| **Objetivo do caso de teste** | Validar que o cartão SD comunica via SPI e permite leitura/escrita de arquivos. |
| **Pré-condições do sistema para o teste ser realizado, quando se aplicar** | Adaptador microSD (CN1) montado, cartão SD formatado em FAT32, ESP32 ligado. |
| **Descrição dos procedimentos a serem executados para o teste** | 1. Energizar o sistema<br>2. Inicializar o barramento SPI (CS, SCK, MOSI, MISO)<br>3. Detectar cartão SD<br>4. Criar/escrever arquivo de teste<br>5. Verificar integridade dos dados |
| **Resultado esperado para o teste ser aprovado (pós-condição após realizado o teste)** | Cartão é detectado corretamente, arquivos são escritos e lidos sem corrupção de dados. |
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

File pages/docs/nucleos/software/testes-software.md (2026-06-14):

# 7.5 — Testes de Software

> Documentação dos testes unitários, de integração e E2E do Sistema Web do Micromouse.

---

## 1. Ferramentas Utilizadas

### Backend (Python)

| Ferramenta | Versão | Propósito |
|---|---|---|
| `pytest` | 9.0.3 | Framework de testes unitários e de integração |
| `pytest-asyncio` | 1.3.0 | Suporte a testes assíncronos (`async/await`) |
| `pytest-cov` | 7.1.0 | Relatório de cobertura de código |
| `FastAPI TestClient` | (via fastapi 0.136.1) | Testes de endpoints HTTP e WebSocket |
| PostgreSQL (Docker) | 16 | Banco de dados de teste isolado (`db_test`) |

### Frontend (TypeScript/React)

| Ferramenta | Versão | Propósito |
|---|---|---|
| `Vitest` | 4.1.7 | Framework de testes (compatível com Vite) |
| `@testing-library/react` | 16.3.2 | Renderização e interação com componentes React |
| `@testing-library/jest-dom` | 6.9.1 | Matchers DOM (`.toBeInTheDocument()`, etc.) |
| `@testing-library/user-event` | 14.6.1 | Simulação de eventos de usuário |
| `@vitest/coverage-v8` | 4.1.7 | Cobertura de código via V8 |
| `jsdom` | 29.1.1 | Ambiente de DOM simulado para testes |

### E2E — Sistema (TypeScript)

| Ferramenta | Versão | Propósito |
|---|---|---|
| `Playwright` | 1.52.0 | Framework de testes E2E em navegador real |
| `@playwright/test` | 1.52.0 | Runner de testes, asserções e fixtures |
| Chromium | (bundled) | Navegador utilizado na execução dos testes |

> Os testes E2E executam sobre a aplicação web em execução local (`http://localhost:5173`). A comunicação WebSocket é simulada via evento customizado `ws-test-message`, permitindo testar fluxos de telemetria sem dependência do hardware físico ou do backend ativo.

---

## 2. Suítes de Testes do Backend

### 2.1 Testes Unitários

#### `test_telemetria.py` — Lógica dos Indicadores de Desempenho

| Classe | Casos | Descrição |
|---|---|---|
| `TestIdentificarTipoPacote` | 10 | Identifica tipo dos pacotes (0–5, inválidos, None, sem campo `tipo`) |
| `TestValidarPacote` | 15 | Valida campos obrigatórios, ranges de bateria, timestamp regressivo, bitmask `w`, dimensão |
| `TestCalcularVelocidadeSegmento` | 6 | Velocidade entre dois pontos, delta_t ≤ 0, diagonal, sem deslocamento |
| `TestCriarEstadoInicial` | 2 | Estado inicial com status `AGUARDANDO` e campos zerados |
| `TestAtualizarIndicadores` | 15 | Processamento de pacotes: atualiza bateria, velocidade, tempo, alertas; imutabilidade |
| `TestCenariosSimulados` | 6 | Corrida completa, bateria crítica, parada inesperada, pacotes inválidos |

**Módulos cobertos:** `app/services/telemetria.py`, `app/schemas/telemetria.py`  
**HUs relacionadas:** US-05 (Indicadores de Desempenho), US-07 (Alertas Funcionais)

#### `test_connection_monitor.py` — Monitoramento de Conexão

| Classe | Casos | Descrição |
|---|---|---|
| `TestConnectionState` | 5 | Estado inicial online, touch, timeout com valores customizados |
| `TestRegistrarPacote` | 3 | Nova corrida online, atualização de last_seen, restauração após offline |
| `TestCheckTimeouts` | 3 | Timeout após 3s, não-timeout recente, offline não re-notifica |
| `TestRemoverCorrida` | 2 | Remoção limpa estado, remoção inexistente não falha |
| `TestNotificacaoWebSocket` | 2 | Formato correto para online e offline |
| `TestFluxoCompleto` | 2 | Ciclo online→offline→online, múltiplas corridas independentes |

**Módulos cobertos:** `app/services/connection_monitor.py`  
**HU relacionada:** US-09 (Monitoramento de Conexão)

#### `test_novos_pacotes.py` — Heartbeat e Alerta de Temperatura

| Classe | Casos | Descrição |
|---|---|---|
| `TestIdentificarTiposNovos` | 2 | Identificação de tipo 4 (Heartbeat) e tipo 5 (AlertaTemperatura) |
| `TestValidarHeartbeat` | 5 | Validação de campos do Heartbeat: bateria obrigatória, range, tipo |
| `TestValidarAlertaTemperatura` | 4 | Validação de `temp_c`: obrigatório, numérico, aceita int |
| `TestProcessarHeartbeat` | 5 | Atualiza bateria/timestamp, não muda status, alerta bateria crítica |
| `TestProcessarAlertaTemperatura` | 5 | Aborta corrida, registra log, seta flag, fixa tempo, não aborta se já encerrada |

**Módulos cobertos:** `app/services/telemetria.py` (processamento de pacotes 4 e 5)  
**HU relacionada:** US-10 (Heartbeat), US-11 (Alerta de Temperatura)

#### `test_alertas_funcionais.py` — Persistência de Alertas

| Função | Casos | Descrição |
|---|---|---|
| `test_alerta_bateria_critica_e_persistido` | 1 | Alerta de bateria crítica persiste como Evento no banco |
| `test_alerta_parada_inesperada_e_persistido` | 1 | Alerta de parada inesperada persiste como Evento |
| `test_alerta_de_parada_nao_dispara_fora_de_corrida_ativa` | 1 | Não emite alerta quando corrida não está EM_ANDAMENTO |

**Módulos cobertos:** `app/routers/telemetria.py` (função `_persistir_novos_alertas`)  
**HU relacionada:** US-07 (Alertas Funcionais)

### 2.2 Testes de Integração

#### `test_persistencia.py` — Persistência no Banco de Dados

| Classe | Casos | Descrição |
|---|---|---|
| `TestIniciarCorrida` | 4 | Cria labirinto e corrida, tipos 4×4 e 16×16, data de início |
| `TestSalvarCorrida` | 5 | Salva campos básicos, resultado de falha, percurso via células, validação de tempo negativo, corrida inexistente |
| `TestPersistenciaFluxoTelemetria` | 9 | Fluxo completo HTTP: pacote inicial cria corrida, movimentação registra percurso, rota otimizada, reutiliza célula, pacote final salva tempo/resultado/velocidade, pacote inválido não persiste |

**Módulos cobertos:** `app/services/registro.py`, `app/routers/telemetria.py`, `app/models/*`  
**HU relacionada:** US-06 (Persistência de Dados), US-12 (Consulta de Corridas)

#### `test_telemetria_router.py` — Endpoints HTTP

| Função | Casos | Descrição |
|---|---|---|
| `test_fluxo_telemetria_completo_sucesso` | 1 | Fluxo completo: inicial → movimentação → final |
| `test_falhas_validacao_barreira` | 8 | Parametrizado: falta tipo, tipo desconhecido, timestamp negativo, dimensão inválida, bateria fora do limite, sucesso não booleano, v_med negativo, w fora do range |
| `test_falha_timestamp_regressivo_isolado` | 1 | Timestamp regressivo retorna 422 |
| `test_pacote_nao_inicial_sem_sessao_ativa` | 1 | Pacote não-inicial sem sessão retorna 409 |

**Módulos cobertos:** `app/routers/telemetria.py` (endpoint `/api/telemetria/pacote`)  
**HU relacionada:** US-04 (Recepção de Telemetria)

#### `test_websocket.py` — Comunicação WebSocket

| Função | Casos | Descrição |
|---|---|---|
| `test_websocket_connection` | 1 | Conecta ao WebSocket e recebe HANDSHAKE |
| `test_telemetry_post_endpoint` | 1 | POST de pacote retorna 201 com alerta de bateria crítica |
| `test_websocket_message_delivery` | 1 | Pacote HTTP é entregue via WebSocket ao dashboard |

**Módulos cobertos:** `app/routers/telemetria.py` (WebSocket), `app/services/websocket_manager.py`  
**HU relacionada:** US-04 (Recepção de Telemetria), US-05 (Dashboard em Tempo Real)

#### `test_novos_pacotes.py` — Integração HTTP (Heartbeat e Temperatura)

| Classe | Casos | Descrição |
|---|---|---|
| `TestHeartbeatRouter` | 4 | Heartbeat retorna 201, sem sessão retorna 409, atualiza bateria, persiste alerta |
| `TestAlertaTemperaturaRouter` | 6 | Alerta retorna 201, encerra sessão, sem sessão retorna 409, marca corrida como abortada, persiste evento, sem temp_c retorna 422 |

**Módulos cobertos:** `app/routers/telemetria.py`  
**HU relacionada:** US-10 (Heartbeat), US-11 (Alerta de Temperatura)

#### `test_melhor_resultado.py` — Endpoint de Melhor Resultado

| Classe | Casos | Descrição |
|---|---|---|
| `TestMelhorResultadoEndpoint` | 7 | Retorna menor tempo, null sem desafio cumprido, corrida abortada excluída, filtro por tipo, campos de rastreabilidade, tipo sem corridas, tipo inválido 422 |

**Módulos cobertos:** `app/routers/labirinto.py`  
**HU relacionada:** US-17 (Melhor Resultado / Recorde)

#### `test_integracao_firmware.py` — Integração Firmware ↔ Backend

| Classe/Função | Casos | Descrição |
|---|---|---|
| `test_cenario_corridas_sequenciais` | 1 | Simula cenário realista com múltiplas corridas no mesmo banco (sucesso, falha, interrupções). |
| `TestContratoTelemetriaMd` | 44 | Valida estritamente os campos e restrições dos pacotes de 0 a 5 com base no documento `telemetria.md`. |
| `TestCenariosAdversos` | 6 | Verifica a resiliência a timestamps regressivos/negativos, baterias inválidas e pacotes sem sessão ativa. |
| `TestBroadcastWebSocket` | 4 | Garante o envio correto dos eventos (`SESSAO_INICIADA`, `MOVIMENTACAO`, `HEARTBEAT`, etc.) via WebSocket. |
| `TestDimensoesLabirinto` | 3 | Valida se as dimensões permitidas (4, 8, 16) mapeiam corretamente para os tipos de labirinto no banco. |
| `test_recuperacao_apos_crash_servidor` | 1 | Verifica se uma corrida em andamento é recuperada corretamente do banco após o servidor reiniciar. |
| `test_recuperacao_mantem_historico_movimentacao_no_banco` | 1 | Garante que todo o histórico de movimentação (antes e depois do crash) persista na mesma corrida. |

**Módulos cobertos:** Integração ponta-a-ponta, validando contrato (`telemetria.md`), roteamento, persistência e websocket.
**HU relacionada:** HU-08, HU-09, HU-10, HU-11, HU-14, HU-15, HU-16, HU-19, HU-20

---

## 3. Suítes de Testes do Frontend

### 3.1 Testes Unitários

#### `DashboardIndicadores.test.tsx` — Cards de Indicadores

| Suíte (CT) | Casos | Descrição |
|---|---|---|
| CT01 — Estado Vazio | 10 | Renderiza labels (Bateria, Controle da Sessão), exibe "--" para valores ausentes, modo "Aguardando", status Offline, sem alertas |
| CT03 — Bateria Crítica | 3 | Exibe banner de alerta, valor real da bateria, abre modal de alerta crítico |
| CT04 — Bateria Normal | 5 | Exibe valor normal, sem banner/modal de alerta, status Online, modo Mapeamento |

**Componente coberto:** `DashboardIndicadores.tsx` (TopIndicators, ControlPanel, TelemetryAlerts)  
**HU relacionada:** US-05 (Indicadores de Desempenho), US-07 (Alertas Visuais)

#### `CardMelhorTempo.test.tsx` — Card de Melhor Resultado

| Suíte (CT) | Casos | Descrição |
|---|---|---|
| CT-CMT-01 — Carregamento | 3 | Exibe "--" durante loading, título "Melhor Resultado" |
| CT-CMT-02 — Estado Vazio | 5 | "Nenhum desafio concluído ainda", sem badge de recorde |
| CT-CMT-03 — Com Recorde | 6 | Exibe id_corrida, tempo formatado, data, badge "Recorde registrado", labels |
| CT-CMT-04 — Estado de Erro | 3 | Exibe mensagem de erro, sem título |

**Componente coberto:** `CardMelhorTempo.tsx`  
**HU relacionada:** US-17 (Melhor Resultado / Recorde)

#### `formatarTempo.test.ts` — Formatação de Tempo

| Suíte (CT) | Casos | Descrição |
|---|---|---|
| CT02 — formatarTempo | 14 | undefined/null/NaN/negativo → "00:00.000"; formatação de segundos, minutos, padding; acima de 60 min |

**Função coberta:** `formatarTempo()` (lógica de apresentação)  
**HU relacionada:** US-05 (Indicadores de Desempenho)

#### `normalizePathToOrthogonal.test.ts` — Normalização de Caminho

| Suíte | Casos | Descrição |
|---|---|---|
| normalizePathToOrthogonal | 11 | Array vazio, ponto único, trajeto ortogonal, diagonal simples/grande, múltiplas diagonais, mix, direção inversa, pontos duplicados |

**Função coberta:** `normalizePathToOrthogonal()` em `mazeUtils.ts`  
**HU relacionada:** HU-12 (Exibição do Trajeto)
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

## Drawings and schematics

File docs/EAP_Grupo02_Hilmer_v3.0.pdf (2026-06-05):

# MICROMOUSE

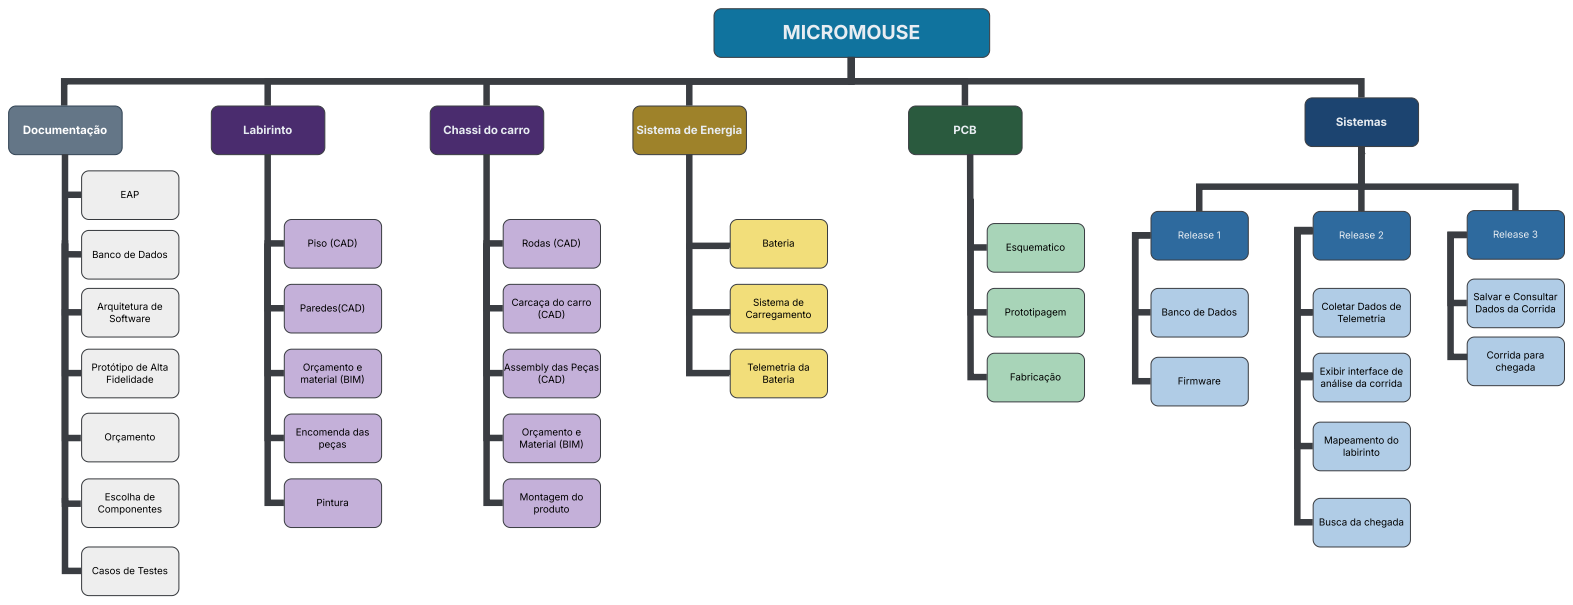
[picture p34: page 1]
Labirinto; Chassi do carro; Sistemas; Sistema de Energia; PCB; Piso (CAD); Paredes(CAD); Orçamento e material (BIM); Encomenda das peças; Pintura; Esquematico; Release 1; Prototipagem; Release 2; Release 3; Fabricação; Rodas (CAD); (CAD); Orçamento e Material (BIM); Montagem do produto; Corrida para; Bateria; Sistema de Carregamento; Telemetria da Bateria; Documentação; Arquitetura de Software; EAP; Orçamento; Firmware; Mapeamento do labirinto; Escolha de Componentes

Banco de Dados

Carcaça do carro
(CAD)

Salvar e Consultar
Dados da Corrida

Coletar Dados de
Telemetria

Protótipo de Alta
Fidelidade

Assembly das Peças

chegada Exibir interface de
análise da corrida

Busca da chegada

Casos de Testes

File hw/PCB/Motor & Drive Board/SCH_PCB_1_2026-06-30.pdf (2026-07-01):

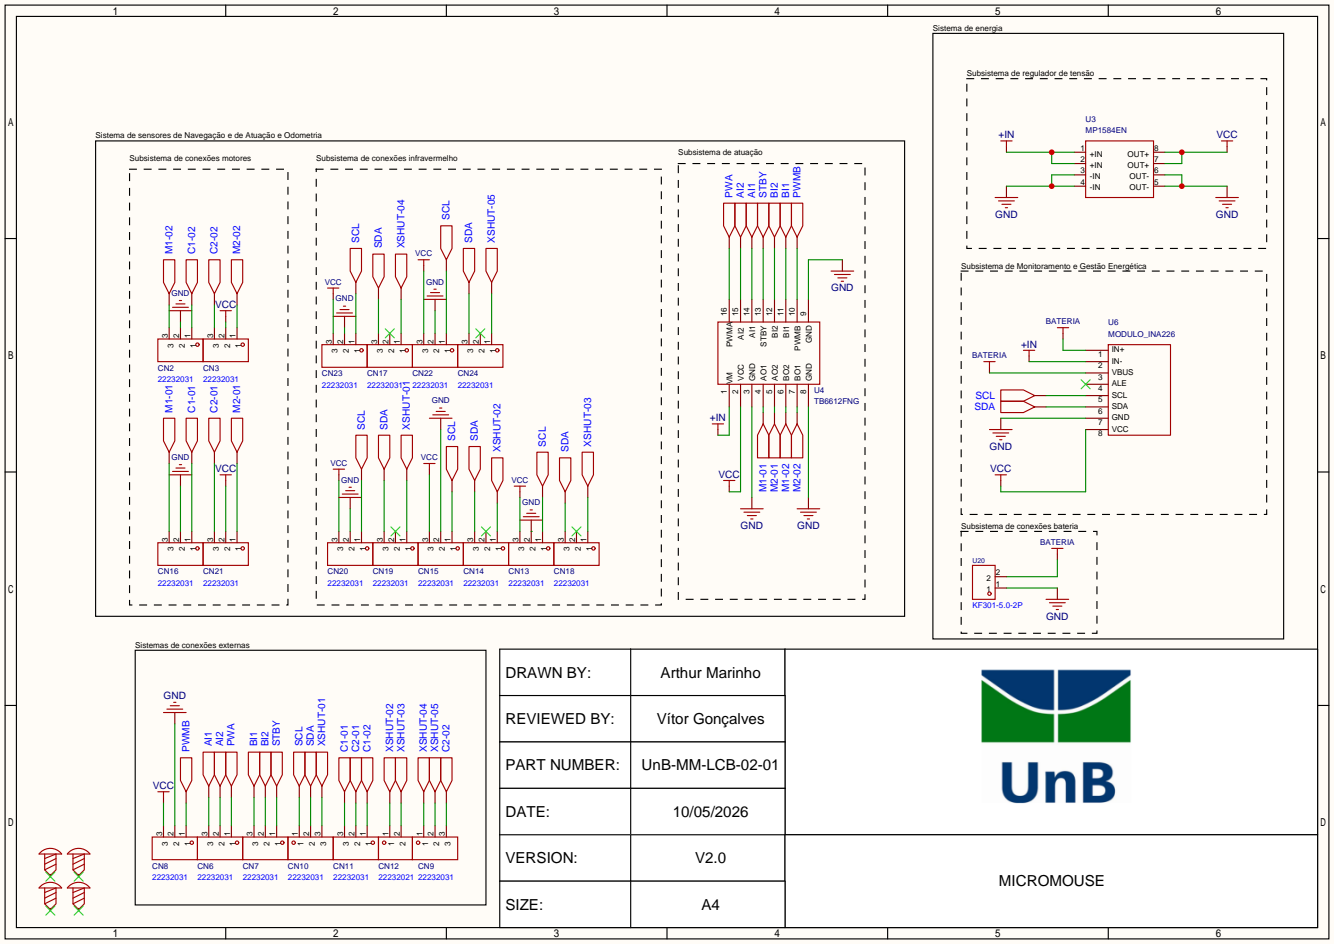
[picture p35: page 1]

Subsistema de regulador de tensão

Sistema de sensores de Navegação e de Atuação e Odometria

Subsistema de atuação PWA AI2 AI1

Subsistema de Monitoramento e Gestão Energética

9 PWMB 10 BI1 11 BI2 12 STBY 13 AI1 14 AI2 15 PWMA 16 GND

Subsistema de conexões bateria

Sistemas de conexões externas

DRAWN BY: | Arthur Marinho

REVIEWED BY: | Vítor Gonçalves

PART NUMBER: | UnB-MM-LCB-02-01

DATE: | 10/05/2026

VERSION: | V2.0 | MICROMOUSE

SIZE: | A4

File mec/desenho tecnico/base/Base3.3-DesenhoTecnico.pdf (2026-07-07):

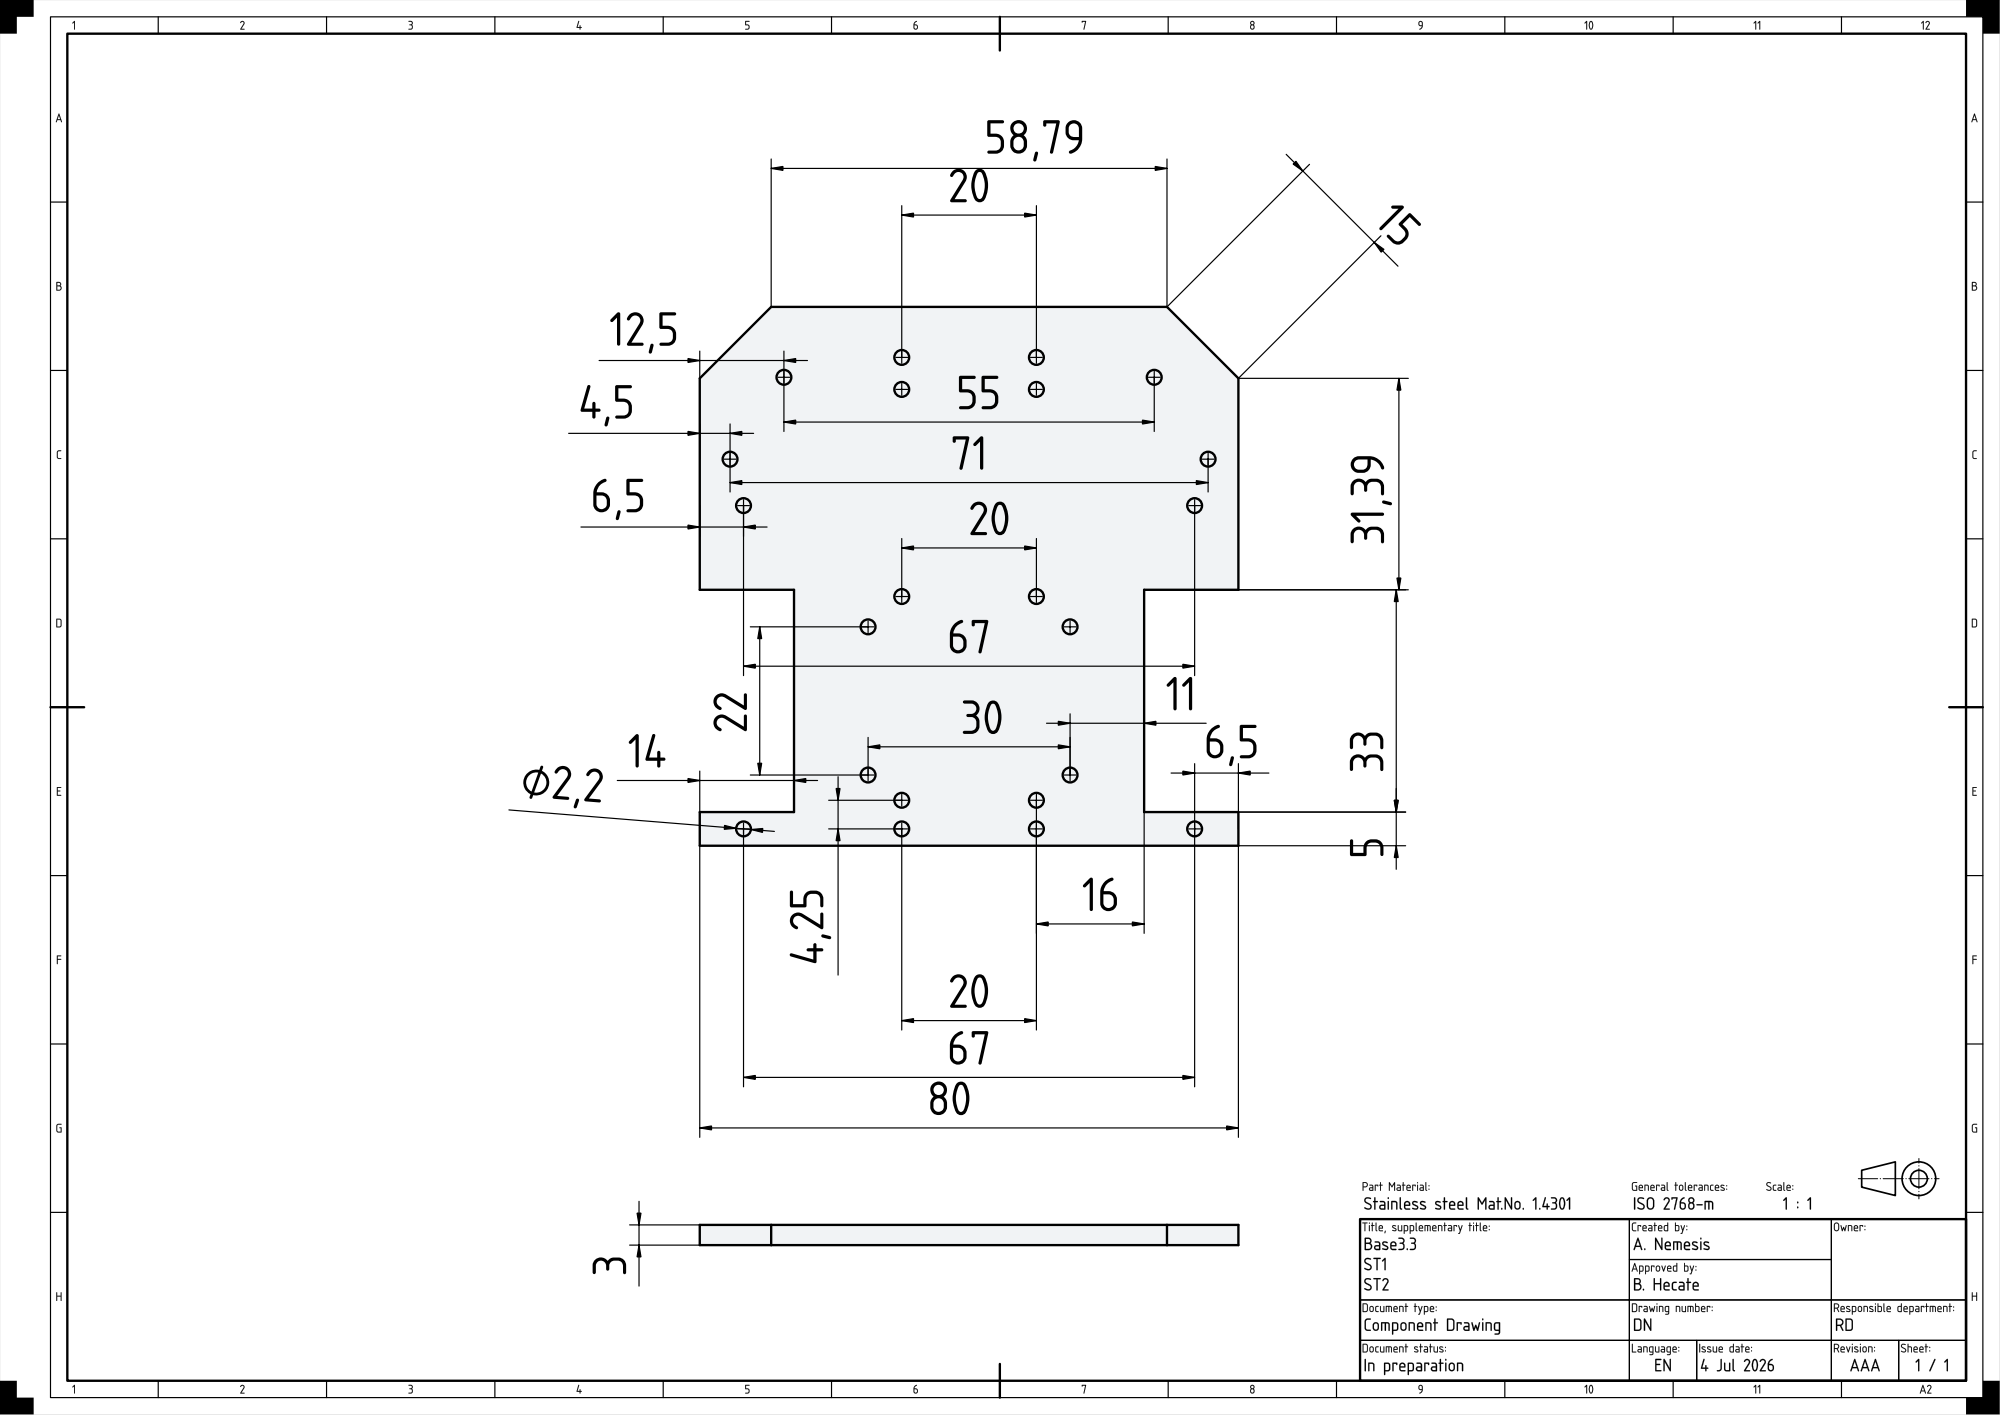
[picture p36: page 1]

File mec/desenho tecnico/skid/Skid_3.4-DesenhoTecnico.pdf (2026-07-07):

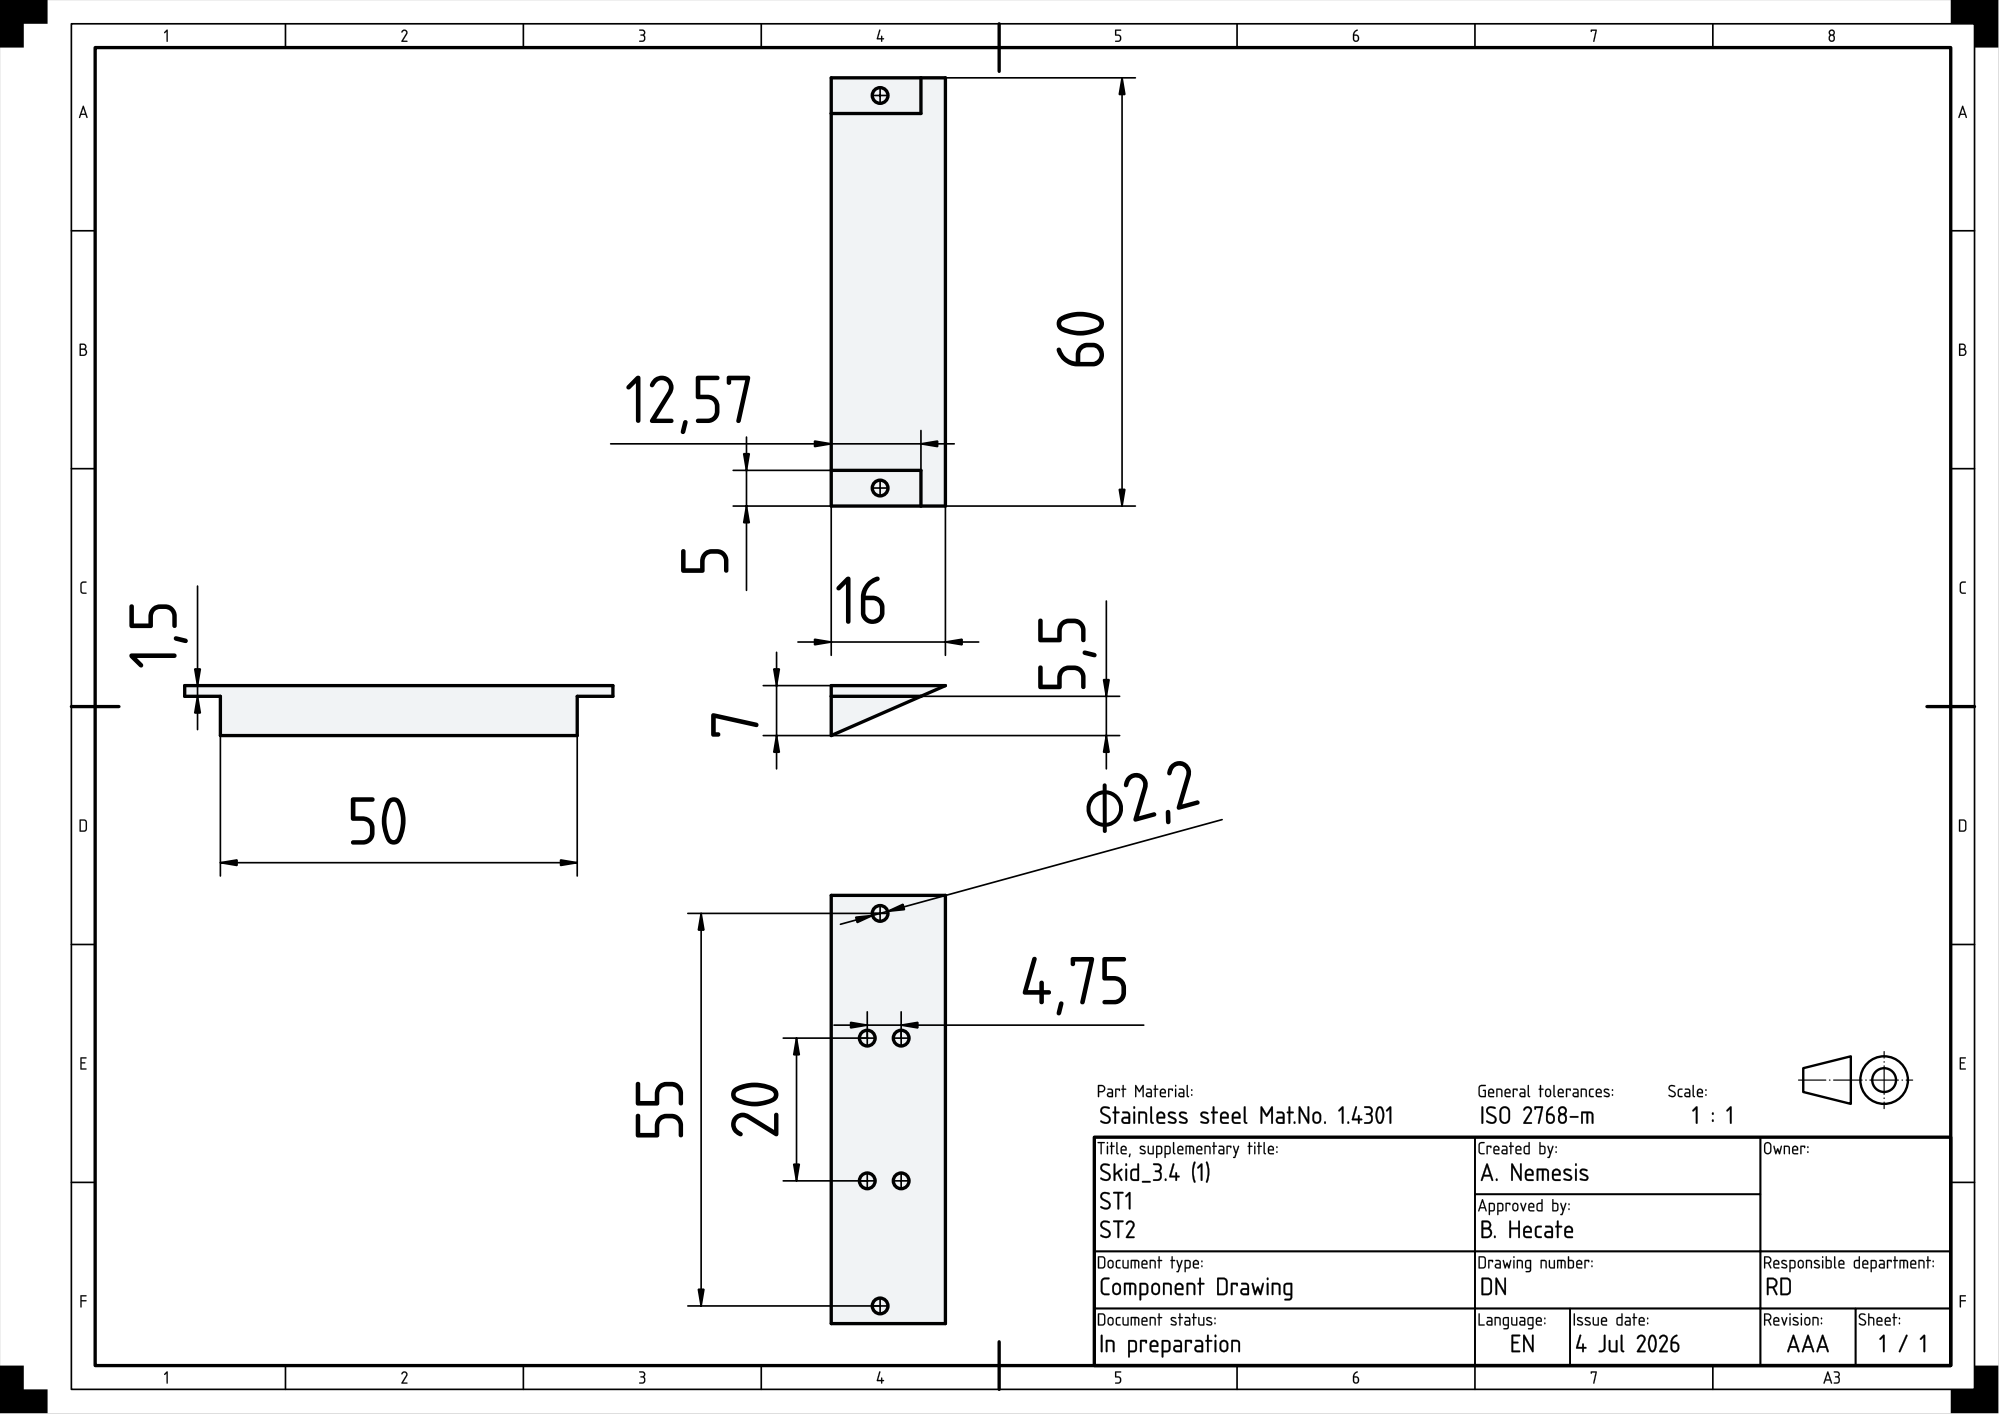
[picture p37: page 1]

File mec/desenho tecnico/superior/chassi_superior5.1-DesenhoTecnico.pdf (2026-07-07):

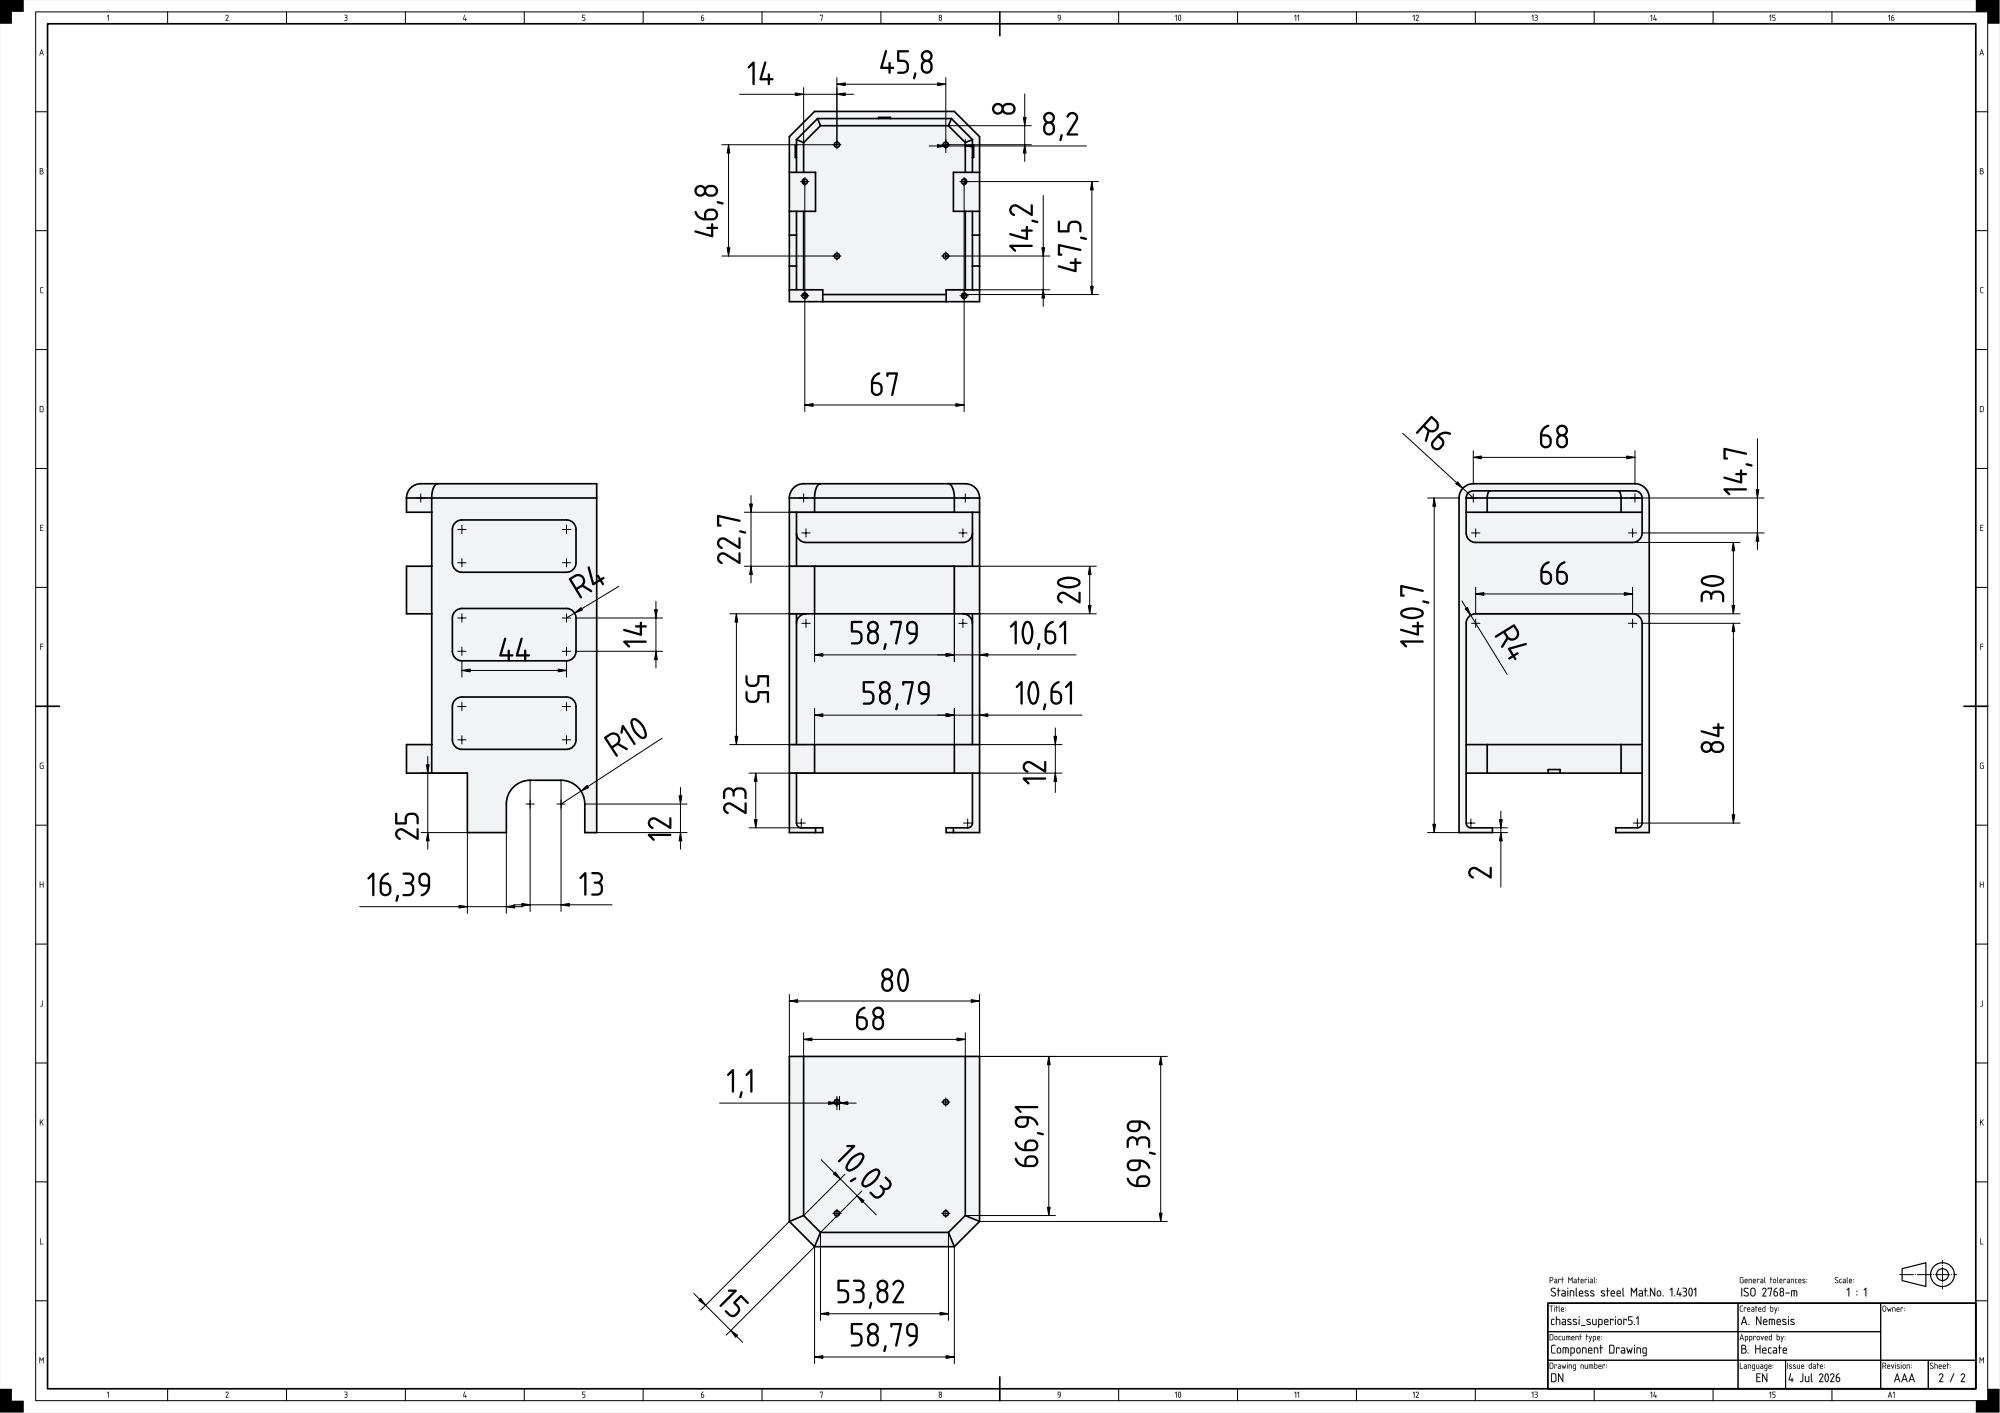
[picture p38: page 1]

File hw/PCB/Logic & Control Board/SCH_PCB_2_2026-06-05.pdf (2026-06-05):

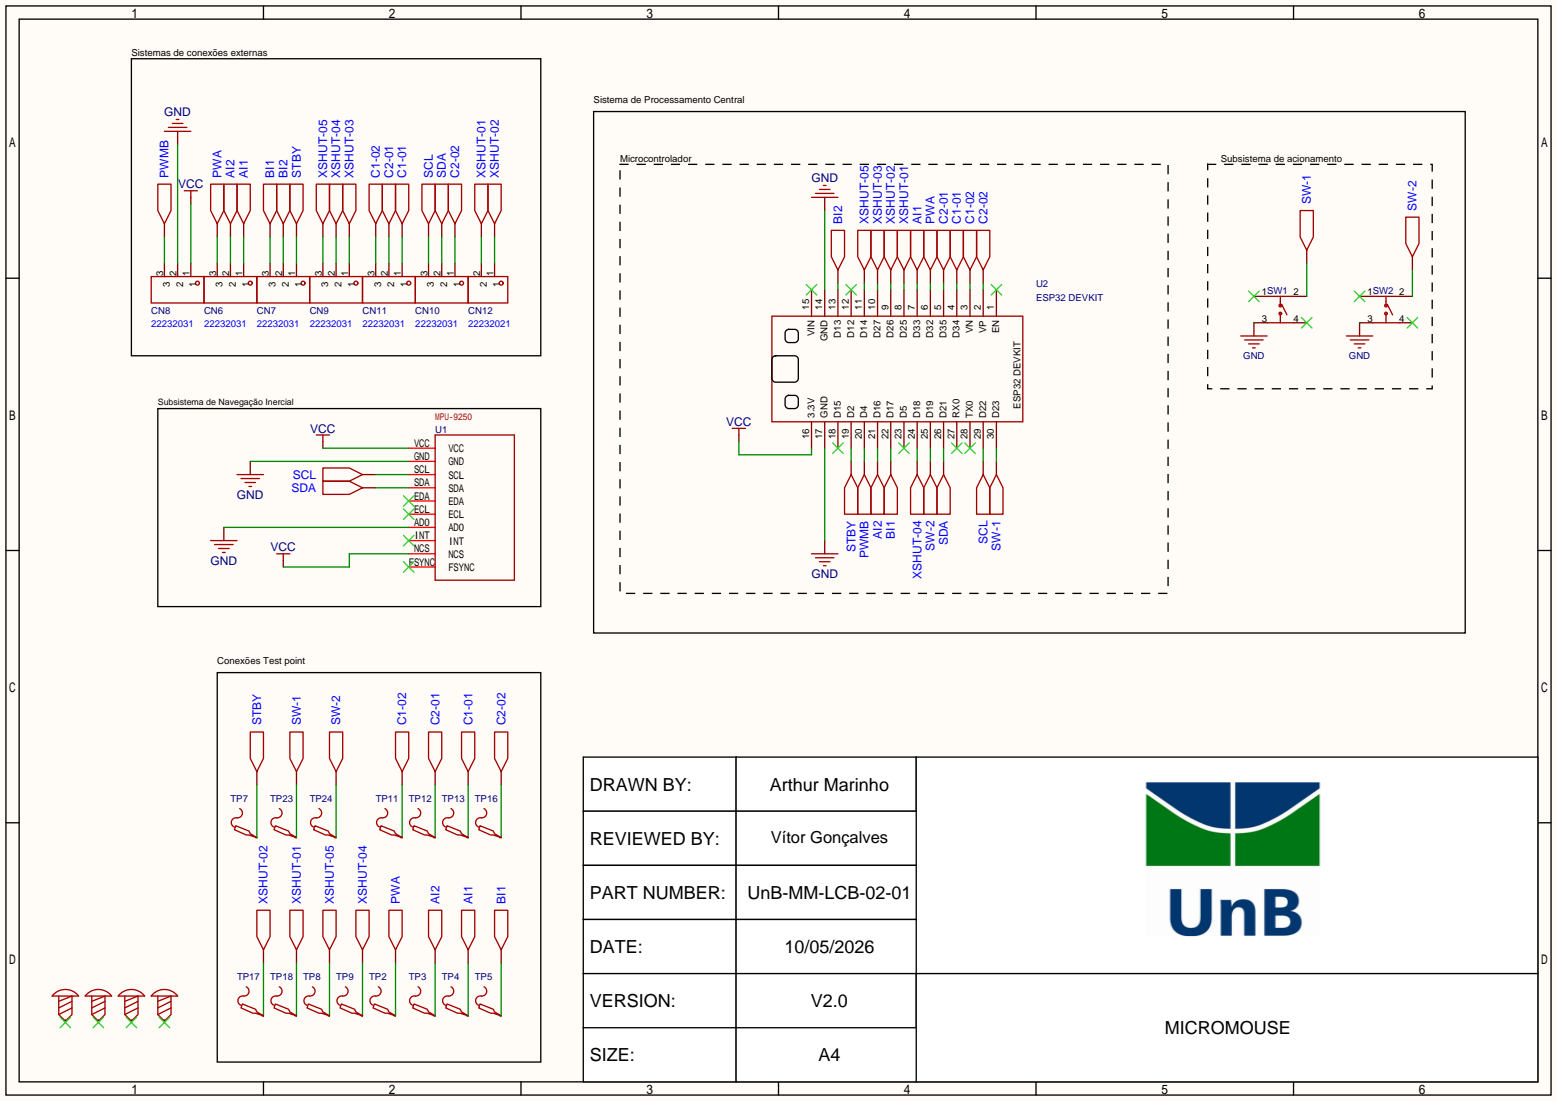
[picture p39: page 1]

Sistemas de conexões externas

Sistema de Processamento Central

Subsistema de Navegação Inercial

DRAWN BY: | Arthur Marinho

REVIEWED BY: | Vítor Gonçalves

PART NUMBER: | UnB-MM-LCB-02-01

DATE: | 10/05/2026

VERSION: | V2.0 | MICROMOUSE

SIZE: | A4

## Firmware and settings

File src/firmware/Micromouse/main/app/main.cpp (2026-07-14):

//  ATENCAO: as constantes marcadas com "CALIBRAR" dependem da geometria fisica
//  do robo e PRECISAM ser ajustadas/medidas no hardware antes da primeira corrida.

#include <atomic>
#include <cstdio>
#include <cmath>

#include "driver/gpio.h"
#include "driver/ledc.h"
#include "driver/pulse_cnt.h"
#include "esp_log.h"
#include "esp_timer.h"
#include "nvs_flash.h"
#include "freertos/FreeRTOS.h"
#include "freertos/task.h"
#include "freertos/semphr.h"
#include "freertos/queue.h"

#include "pins.hpp"
#include "i2c_manager.hpp"
#include "battery/battery.hpp"
#include "imu.h"
#include "vl53l0x/IV_Vl53l0x.hpp"
#include "maze.hpp"
#include "telemetria.hpp"
#include "botoes/botoes.hpp"

namespace {

static const char* TAG = "MAIN";

//  Configuracao da rede / backend
const char* WIFI_SSID   = "NOME_DO_SEU_WIFI";
const char* WIFI_PASS   = "SENHA_DO_SEU_WIFI";
const char* BACKEND_URL = "http://192.168.1.50:8000/api/telemetria";

//  Constantes de movimento  (CALIBRAR NO HARDWARE)
constexpr int   PWM_MAX            = 1023;   // resolucao 10 bits (LEDC_TIMER_10_BIT)

// Quantas contagens de encoder (media das 2 rodas) equivalem a avançar uma
// celula do labirinto (~18 cm). MEDIR: ande 1 celula e leia o encoder. CALIBRAR.
constexpr int   COUNTS_PER_CELL    = 1000;

// Distancia (mm) abaixo da qual consideramos que existe parede naquela direcao.
constexpr float WALL_THRESHOLD_MM  = 120.0f;  // CALIBRAR conforme a celula
// Distancia (mm) de seguranca: para o avanco se houver parede colada na frente.
constexpr float FRONT_STOP_MM      = 55.0f;   // CALIBRAR

constexpr int   DRIVE_PWM          = PWM_MAX / 2; // velocidade de avanco
constexpr int   TURN_PWM           = PWM_MAX / 3; // velocidade de giro
constexpr float TURN_TARGET_RAD    = M_PI / 2.0f; // 90 graus por passo de giro
// --- Fusao sensorial (encoder + gyro) para estimar o rumo (heading) ---
// Peso do gyro no filtro complementar (0..1). Perto de 1 confia mais no gyro
// no curto prazo; o restante (1-alpha) deixa o encoder corrigir a deriva.
constexpr float HEADING_ALPHA      = 0.98f;
// Ganho da correcao de rumo no avanco reto (desvio de PWM por rad de erro).
constexpr float KP_HEADING         = 400.0f;     // CALIBRAR
// Geometria para converter contagens de encoder em rotacao do robo.
constexpr float WHEEL_DIAMETER_M     = 0.0298f;   // CALIBRAR: diametro da roda (m)
constexpr int   COUNTS_PER_WHEEL_REV = 588;      // medido: 147 (1 canal) x4 (quadratura)
constexpr float TRACK_WIDTH_M        = 0.068725f;   // CALIBRAR: distancia entre as rodas (m)
// Metros percorridos por 1 contagem de encoder (de uma roda).
constexpr float METERS_PER_COUNT   = (float)M_PI * WHEEL_DIAMETER_M / COUNTS_PER_WHEEL_REV;

// Tamanho fisico aproximado de uma celula (~18 cm); usado para estimar v_med.
constexpr float CELL_SIZE_M        = 0.18f;
// Limiar de temperatura do IMU acima do qual a corrida e abortada (alerta tipo 5).
constexpr float TEMP_CRITICA_C     = 60.0f;       // CALIBRAR conforme o hardware

//  Recursos compartilhados
SemaphoreHandle_t g_i2c_mutex = nullptr;   // serializa o barramento I2C

Battery   g_battery;
Labirinto g_labirinto;
Telemetria g_telemetria(BACKEND_URL, 1500); // heartbeat de 1,5 s

// Tamanhos de labirinto que o botao 2 cicla, em ordem. Comeca em 4x4.
// (O 16x16 foi removido dos requisitos do projeto.)
const Labirinto::Tamanho kTamanhos[] = {
    Labirinto::Tamanho::k4x4,
    Labirinto::Tamanho::k8x8,
};
constexpr int kNumTamanhos = sizeof(kTamanhos) / sizeof(kTamanhos[0]);
int g_idx_tamanho = 0; // 4x4 por padrao

// Sincronizacao botao <-> telemetria. A largada (1o clique do botao 1) escolhe
// o tamanho; so entao a telemetria conecta o Wi-Fi e envia a config inicial
// (tipo 0) com o tamanho correto e o relogio da corrida zerado no instante real.
std::atomic<bool> g_largada_dada{false};      // navegacao -> telemetria
std::atomic<bool> g_telemetria_pronta{false}; // telemetria -> navegacao

// Eventos de telemetria: a navegacao enfileira, a telemetria_task faz o HTTP.
struct EventoTelemetria {
    enum class Tipo : uint8_t { Movimento, Rota, FimCorrida, AlertaTemperatura };
    Tipo tipo;
    union {
        struct { uint8_t x, y, paredes; } mov;
        struct { uint16_t n; Labirinto::Coordenada pontos[Labirinto::kMaxCaminho]; } rota;
        struct { bool sucesso; float v_med; int bateria; } fim;
        struct { float temp_c; } alerta;
    };
};
constexpr int kFilaTelemetriaLen = 12;
QueueHandle_t g_fila_telemetria = nullptr;

// Ordem de boot em cascata.
// O robo usa apenas 3 ToFs: frente, esquerda e direita (os laterais a 90 graus).
IV_Vl53l0x g_tof_front({
    .position = IV_Vl53l0x::Position::FRONT,
    .address = I2C_ADDR_VL53L0X_ALT_0, .xshut_pin = TOF_FRONT_XSHUT_PIN,
    .i2c_speed_hz = I2C_MANAGER_DEFAULT_SPEED_HZ, .timing_budget_ms = 20,
    .log_level = espp::Logger::Verbosity::WARN,
});
IV_Vl53l0x g_tof_left({
    .position = IV_Vl53l0x::Position::LEFT,
    .address = I2C_ADDR_VL53L0X_ALT_3, .xshut_pin = TOF_LEFT_XSHUT_PIN,
    .i2c_speed_hz = I2C_MANAGER_DEFAULT_SPEED_HZ, .timing_budget_ms = 20,
    .log_level = espp::Logger::Verbosity::WARN,
});
IV_Vl53l0x g_tof_right({
    .position = IV_Vl53l0x::Position::RIGHT,
    .address = I2C_ADDR_VL53L0X_ALT_4, .xshut_pin = TOF_RIGHT_XSHUT_PIN,
    .i2c_speed_hz = I2C_MANAGER_DEFAULT_SPEED_HZ, .timing_budget_ms = 20,
    .log_level = espp::Logger::Verbosity::WARN,
});

// Motores/encoders
pcnt_unit_handle_t s_pcnt_unit_r = nullptr;
pcnt_unit_handle_t s_pcnt_unit_l = nullptr;
volatile int32_t   s_enc_total_r = 0, s_enc_total_l = 0;
volatile int16_t   s_enc_last_r  = 0, s_enc_last_l  = 0;

// Estimativa de rumo (heading) fundindo gyro + encoder (filtro complementar).
volatile float     g_heading_rad = 0.0f;
int32_t            s_head_last_l = 0, s_head_last_r = 0;
int64_t            s_head_t_prev = 0;

//  Pose do robo no labirinto
enum Heading : uint8_t { NORTE = 0, LESTE = 1, SUL = 2, OESTE = 3 };

struct Pose {
    uint8_t x = 0;
    uint8_t y = 0;
    Heading heading = NORTE;
};
Pose g_pose;

// Deslocamento (dx, dy) de cada direcao absoluta; usado por avancarUmaCelula.
const int8_t kHeadingDx[4] = {0, +1, 0, -1};
const int8_t kHeadingDy[4] = {+1, 0, -1, 0};

// Snapshots compartilhados entre tasks (um unico escritor por campo).
std::atomic<int>   g_snap_soc{100};
std::atomic<float> g_snap_temp{0.0f};

const char* nomeDirecao(Heading h) {
    switch (h) {
        case NORTE: return "N";
        case LESTE: return "L";
        case SUL:   return "S";
        case OESTE: return "O";
    }
    return "N";
}

//  Controle raw dos motores
void pwm_left(uint32_t duty) {
    ledc_set_duty(LEDC_LOW_SPEED_MODE, LEDC_CHANNEL_0, duty);
    ledc_update_duty(LEDC_LOW_SPEED_MODE, LEDC_CHANNEL_0);
}
void pwm_right(uint32_t duty) {
    ledc_set_duty(LEDC_LOW_SPEED_MODE, LEDC_CHANNEL_1, duty);
    ledc_update_duty(LEDC_LOW_SPEED_MODE, LEDC_CHANNEL_1);
}
void dir_left(bool frente) {
    gpio_set_level(MOTOR_LEFT_IN1_PIN, frente ? 1 : 0);
    gpio_set_level(MOTOR_LEFT_IN2_PIN, frente ? 0 : 1);
}
void dir_right(bool frente) {
    gpio_set_level(MOTOR_RIGHT_IN1_PIN, frente ? 1 : 0);
    gpio_set_level(MOTOR_RIGHT_IN2_PIN, frente ? 0 : 1);
}
void motores_para() {
    pwm_left(0);
    pwm_right(0);
    gpio_set_level(MOTOR_LEFT_IN1_PIN, 0);
    gpio_set_level(MOTOR_LEFT_IN2_PIN, 0);
    gpio_set_level(MOTOR_RIGHT_IN1_PIN, 0);
    gpio_set_level(MOTOR_RIGHT_IN2_PIN, 0);
}

void encoder_read() {
    int raw_r = 0, raw_l = 0;
    pcnt_unit_get_count(s_pcnt_unit_r, &raw_r);
    pcnt_unit_get_count(s_pcnt_unit_l, &raw_l);
    int16_t cur_r = (int16_t)raw_r;
    int16_t cur_l = (int16_t)raw_l;
    s_enc_total_r += (cur_r - s_enc_last_r);
    s_enc_total_l += (cur_l - s_enc_last_l);
    s_enc_last_r = cur_r;
    s_enc_last_l = cur_l;
}
void encoder_reset() {
    pcnt_unit_clear_count(s_pcnt_unit_r);
    pcnt_unit_clear_count(s_pcnt_unit_l);
    s_enc_total_r = 0;
    s_enc_total_l = 0;
    s_enc_last_r  = 0;
    s_enc_last_l  = 0;
}

//  Leitura dos sensores
struct LeituraToF {
    float frente;
    float esquerda;
    float direita;
};

// Le um ToF segurando o mutex I2C so durante a medicao.
float lerUmToF(IV_Vl53l0x& tof) {
    if (xSemaphoreTake(g_i2c_mutex, pdMS_TO_TICKS(150)) != pdTRUE) {
        ESP_LOGW(TAG, "lerUmToF(%s): perdeu a vez no I2C", tof.positionName().data());
        return 9999.0f;
    }
    const float mm = tof.readDistanceMm();
    xSemaphoreGive(g_i2c_mutex);
    return mm;
}

LeituraToF lerToFs() {
    LeituraToF l;
    l.frente   = lerUmToF(g_tof_front);
    l.esquerda = lerUmToF(g_tof_left);
    l.direita  = lerUmToF(g_tof_right);
    return l;
}

// Le o gyro_z (rad/s) ja sem o bias de calibracao. Retorna false se falhar.
bool lerGyroZ(float* gz_out, float* temp_out) {
    if (xSemaphoreTake(g_i2c_mutex, pdMS_TO_TICKS(50)) != pdTRUE) return false;
    const bool ok = imu_update();
    if (ok) {
        const DadosIMU d = imu_get_dados();
        if (gz_out)   *gz_out   = d.gyro_z;
        if (temp_out) *temp_out = d.temperatura;
    }
    xSemaphoreGive(g_i2c_mutex);
    return ok;
}

//  Fusao sensorial: estimador de rumo (heading)

// Zera o rumo e captura o estado atual de encoders/tempo. Chame no inicio de
// cada manobra (avanco ou giro) para medir a rotacao a partir do zero.
void heading_reset() {
    encoder_read();
    g_heading_rad = 0.0f;
    s_head_last_l = s_enc_total_l;
    s_head_last_r = s_enc_total_r;
    s_head_t_prev = esp_timer_get_time();
}

// Funde gyro (curto prazo) + encoder diferencial (ancora de longo prazo) por
// filtro complementar e devolve o rumo acumulado, em rad. Tambem atualiza os
// s_enc_total_* (chama encoder_read internamente).
//   Convencao: gyro_z > 0 e (roda direita avanca mais que a esquerda) => giro
//   anti-horario (CCW) = rumo positivo. Se vier invertido no hardware, troque
//   o sinal de dth_enc (ou confira o sinal do gyro_z).
float heading_update() {
    encoder_read();
    const int64_t now = esp_timer_get_time();
    float dt = (now - s_head_t_prev) / 1e6f;
    if (dt <= 0.0f) dt = 1e-3f;
    s_head_t_prev = now;

    // Incremento pelo gyro (rad).
    float gz = 0.0f;
    const bool gyro_ok = lerGyroZ(&gz, nullptr);

    // Incremento pelo encoder diferencial (rad).
    const int32_t dl = s_enc_total_l - s_head_last_l;
    const int32_t dr = s_enc_total_r - s_head_last_r;
    s_head_last_l = s_enc_total_l;
    s_head_last_r = s_enc_total_r;
    const float dth_enc = (float)(dr - dl) * METERS_PER_COUNT / TRACK_WIDTH_M;

    if (gyro_ok) {
        // Filtro complementar: gyro domina o curto prazo, encoder ancora a deriva.
        g_heading_rad += HEADING_ALPHA * (gz * dt) + (1.0f - HEADING_ALPHA) * dth_enc;
    } else {
        // Sem gyro neste intervalo: usa so o encoder (integrar zero passaria do ponto).
        g_heading_rad += dth_enc;
    }
    return g_heading_rad;
}

//  Primitivas de movimento

// Gira em torno do proprio eixo fechando o angulo pela integracao do gyro.
//   passos > 0  -> sentido horario  (vira a direita) em multiplos de 90 graus
//   passos < 0  -> sentido anti-horario (vira a esquerda)
void girar(int passos) {
    if (passos == 0) return;
    const bool horario = passos > 0;
    const float alvo   = std::fabs((float)passos) * TURN_TARGET_RAD;

    // Spin no proprio eixo: rodas em sentidos opostos.
    dir_left(horario);    // horario: esquerda p/ frente, direita p/ tras
    dir_right(!horario);
    pwm_left(TURN_PWM);
    pwm_right(TURN_PWM);

    // Fecha o angulo pelo rumo fundido (gyro + encoder).
    heading_reset();
    const int64_t t_start = esp_timer_get_time();
    const int64_t timeout_us = 4000000; // 4 s de seguranca

    while (std::fabs(heading_update()) < alvo) {
        if (esp_timer_get_time() - t_start > timeout_us) {
            ESP_LOGW(TAG, "girar(): timeout (ang=%.2f rad)", std::fabs(g_heading_rad));
            break;
        }
        vTaskDelay(pdMS_TO_TICKS(5));
    }

    motores_para();
    vTaskDelay(pdMS_TO_TICKS(120)); // assenta a inercia

    g_pose.heading = (Heading)(((int)g_pose.heading + passos + 4 * 4) % 4);
}

// Vira para uma direcao absoluta escolhendo o menor giro.
void virarPara(Heading destino) {
    int diff = ((int)destino - (int)g_pose.heading + 4) % 4; // 0..3 horario
    if (diff == 0) return;
    if (diff == 1)      girar(+1);  // direita
    else if (diff == 3) girar(-1);  // esquerda
    else                girar(+2);  // 180 graus
}

// Avanca uma celula fechando a distancia pelos encoders, com correcao reta
// proporcional. Para antes se aparecer parede colada na frente.
void avancarUmaCelula() {
    encoder_reset();
    heading_reset();
    dir_left(true);
    dir_right(true);

    while (true) {
        // Funde gyro + encoder (heading_update tambem atualiza s_enc_total_*).
        const float rumo = heading_update();
        const int32_t avg = (s_enc_total_l + s_enc_total_r) / 2;
        if (avg >= COUNTS_PER_CELL) break;

        // Seguranca: parede colada na frente (so o ToF frontal importa aqui).
        const float frente = lerUmToF(g_tof_front);
        if (frente > 0.0f && frente < FRONT_STOP_MM) {
            ESP_LOGW(TAG, "avancar(): parede a %.0f mm, parando", frente);
            break;
        }

        // Correcao de rumo: mantem o heading em zero (anda reto). rumo > 0
        // (CCW, nariz p/ esquerda) => acelera a esquerda e freia a direita.
        const int corr = (int)(KP_HEADING * rumo);
        int duty_l = DRIVE_PWM + corr;
        int duty_r = DRIVE_PWM - corr;
        if (duty_l < 0) duty_l = 0;
        if (duty_l > PWM_MAX) duty_l = PWM_MAX;
        if (duty_r < 0) duty_r = 0;
        if (duty_r > PWM_MAX) duty_r = PWM_MAX;
        pwm_left(duty_l);
        pwm_right(duty_r);

        vTaskDelay(pdMS_TO_TICKS(5));
    }

    motores_para();
    vTaskDelay(pdMS_TO_TICKS(100));

    // Atualiza a pose so se realmente havia caminho a frente.
    g_pose.x = (uint8_t)(g_pose.x + kHeadingDx[g_pose.heading]);
    g_pose.y = (uint8_t)(g_pose.y + kHeadingDy[g_pose.heading]);
}

//  Eventos de telemetria

// Nao bloqueia: se a fila encher, descarta o evento.
void postarEvento(const EventoTelemetria& ev) {
    if (g_fila_telemetria == nullptr) return;
    if (xQueueSend(g_fila_telemetria, &ev, 0) != pdTRUE) {
        ESP_LOGW(TAG, "Fila de telemetria cheia; evento tipo %d descartado",
                 (int)ev.tipo);
    }
}

void postarMovimento(uint8_t x, uint8_t y, uint8_t paredes) {
    EventoTelemetria ev;
    ev.tipo = EventoTelemetria::Tipo::Movimento;
    ev.mov  = {x, y, paredes};
    postarEvento(ev);
}

void postarRotaOtima() {
    EventoTelemetria ev;
    ev.tipo   = EventoTelemetria::Tipo::Rota;
    ev.rota.n = g_labirinto.rotaOtima(ev.rota.pontos, Labirinto::kMaxCaminho);
    if (ev.rota.n > 0) postarEvento(ev);
}

void postarFimCorrida(bool sucesso, float v_med) {
    EventoTelemetria ev;
    ev.tipo = EventoTelemetria::Tipo::FimCorrida;
    ev.fim  = {sucesso, v_med, g_snap_soc.load()};
    postarEvento(ev);
}

void postarAlertaTemperatura(float temp_c) {
    EventoTelemetria ev;
    ev.tipo   = EventoTelemetria::Tipo::AlertaTemperatura;
    ev.alerta = {temp_c};
    postarEvento(ev);
}

//  Tasks paralelas (bateria + telemetria)
void battery_task(void*) {
    const TickType_t delay = pdMS_TO_TICKS(500);
    while (true) {
        if (xSemaphoreTake(g_i2c_mutex, pdMS_TO_TICKS(150)) == pdTRUE) {
            g_battery.update();
            xSemaphoreGive(g_i2c_mutex);
        }
        g_snap_soc = (int)g_battery.getSOC();
        vTaskDelay(delay);
    }
}

void telemetria_task(void*) {
    // Espera a largada (botao 1) para que o tamanho do labirinto ja esteja
    // definido: a config inicial (tipo 0) sai com o tamanho escolhido e o
    // relogio da corrida zera no instante real do inicio.
    while (!g_largada_dada) vTaskDelay(pdMS_TO_TICKS(20));

    // Conecta ao Wi-Fi (bloqueante) e envia a configuracao inicial (tipo 0).
    g_telemetria.inicializar(WIFI_SSID, WIFI_PASS, g_labirinto, g_snap_soc.load());
    g_telemetria_pronta = true; // libera a navegacao para comecar a se mover

    // Unica task que faz HTTP; heartbeat (tipo 4) nos intervalos ociosos.
    EventoTelemetria ev;
    while (true) {
        if (xQueueReceive(g_fila_telemetria, &ev, pdMS_TO_TICKS(250)) == pdTRUE) {
            switch (ev.tipo) {
                case EventoTelemetria::Tipo::Movimento:
                    g_telemetria.movimento(ev.mov.x, ev.mov.y, ev.mov.paredes);
                    break;
                case EventoTelemetria::Tipo::Rota:
                    g_telemetria.rota_otimizada(ev.rota.pontos, ev.rota.n);
                    break;
                case EventoTelemetria::Tipo::FimCorrida:
                    g_telemetria.fim_corrida(ev.fim.sucesso, ev.fim.v_med,
                                             ev.fim.bateria);
                    break;
                case EventoTelemetria::Tipo::AlertaTemperatura:
                    g_telemetria.alerta_temperatura(ev.alerta.temp_c);
                    break;
            }
        } else {
            g_telemetria.verificar_heartbeat(g_snap_soc.load());
        }
    }
}
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
extern "C" void app_main(void) {
    vTaskDelay(pdMS_TO_TICKS(200));
    ESP_LOGI(TAG, "=== Micromouse :: main de navegacao ===");

    esp_err_t nvs = nvs_flash_init();
    if (nvs == ESP_ERR_NVS_NO_FREE_PAGES || nvs == ESP_ERR_NVS_NEW_VERSION_FOUND) {
        ESP_ERROR_CHECK(nvs_flash_erase());
        nvs = nvs_flash_init();
    }
    ESP_ERROR_CHECK(nvs);

    g_i2c_mutex = xSemaphoreCreateMutex();
    if (g_i2c_mutex == nullptr) {
        ESP_LOGE(TAG, "Falha ao criar o mutex do I2C");
        return;
    }

    g_fila_telemetria = xQueueCreate(kFilaTelemetriaLen, sizeof(EventoTelemetria));
    if (g_fila_telemetria == nullptr) {
        ESP_LOGE(TAG, "Falha ao criar a fila de telemetria");
        return;
    }

    if (!initSensores()) {
        ESP_LOGE(TAG, "Erro fatal na inicializacao dos sensores");
        return;
    }
    if (!initMotores()) {
        ESP_LOGE(TAG, "Erro fatal na inicializacao dos motores");
        return;
    }
    motores_para();

    g_labirinto.configurar(Labirinto::Tamanho::k4x4); // padrao; o botao 2 ajusta

    ESP_LOGI(TAG, "Lancando tasks...");
    // Wi-Fi/lwIP, bateria e telemetria no core 0; navegacao sozinha no core 1.
    xTaskCreatePinnedToCore(battery_task,    "battery",    4096, nullptr, 2, nullptr, 0);
    xTaskCreatePinnedToCore(telemetria_task, "telemetria", 8192, nullptr, 3, nullptr, 0);
    xTaskCreatePinnedToCore(navegacao_task,  "navegacao",  8192, nullptr, 10, nullptr, 1);

    ESP_LOGI(TAG, "=== Sistema pronto ===");
}

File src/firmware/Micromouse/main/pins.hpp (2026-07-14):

#pragma once

#include "driver/gpio.h"

// Barramento I2C compartilhado
#define I2C_SDA_PIN GPIO_NUM_21
#define I2C_SCL_PIN GPIO_NUM_22

// Standby da Ponte H (Ajuste caso use outro pino físico)
#define MOTOR_STBY_PIN        GPIO_NUM_2

// Motor Esquerdo (Lado A)
#define MOTOR_LEFT_PWM_PIN    GPIO_NUM_32
#define MOTOR_LEFT_IN1_PIN    GPIO_NUM_33
#define MOTOR_LEFT_IN2_PIN    GPIO_NUM_16
// Conector C1
#define MOTOR_LEFT_ENC_A_PIN  GPIO_NUM_34 // C1-01
#define MOTOR_LEFT_ENC_B_PIN  GPIO_NUM_35 // C1-02

// Motor Direito (Lado B)
#define MOTOR_RIGHT_PWM_PIN   GPIO_NUM_4
#define MOTOR_RIGHT_IN1_PIN   GPIO_NUM_17
#define MOTOR_RIGHT_IN2_PIN   GPIO_NUM_13
// Conector C2
#define MOTOR_RIGHT_ENC_A_PIN GPIO_NUM_36 // C2-01 (VP)
#define MOTOR_RIGHT_ENC_B_PIN GPIO_NUM_39 // C2-02 (VN)

// Botoes de controle (entrada com pull-down interno; o botao liga o pino ao
// 3V3, portanto sao ativos em nivel ALTO — ver botoes/botoes.cpp).
#define BUTTON_START_PIN  GPIO_NUM_19 // D19: 1o clique mapeia, 2o clique corre
#define BUTTON_SIZE_PIN   GPIO_NUM_23 // D23: cicla o tamanho 4x4 -> 8x8

// Sensores ToF (VL53L0X) — pinos XSHUT
// ATENÇÃO: verifique os pinos abaixo contra o esquemático antes de soldar
#define TOF_FRONT_XSHUT_PIN        GPIO_NUM_25
#define TOF_FRONT_LEFT_XSHUT_PIN   GPIO_NUM_27
#define TOF_FRONT_RIGHT_XSHUT_PIN  GPIO_NUM_14
#define TOF_LEFT_XSHUT_PIN         GPIO_NUM_18
#define TOF_RIGHT_XSHUT_PIN        GPIO_NUM_26

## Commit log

2026-05-18 Feat:. Implementação da lógica e dashboard dos indicadores de desempenho (#282)
    * change main.py
    * fix error in main.py
    * minor changes on files
    * implementa script básico de websocket no frontend
    * fix error on parsing data from json
    * feat: implementacao da logica e dashboard dos indicadores de desempenho
    ---------
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2026-05-18 feat(telemetria): adiciona a lógica de alerta crítico para bateria e paradas inesperadas na telemetria
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2026-05-19 Estudo de redimensionamento de medidas do chassi; Closes: #256
    Document the redesign of the chassis and component organization for the micromouse project, including PCB layout and battery resizing considerations.
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2026-05-20 peça 3D do rolamento
    [rolamento.step]
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2026-05-22 docs(piso8): Piso8
    Piso de 800 mm por 800 mm com paredes de 12 mm de espessura e tamanho interno de 165 mm.
    [Piso8.FCStd]
2026-05-22 docs(paredes): Parede Externa 8
    Parede externa com pinos para encaixe no piso
    [Parede_externa_8.FCStd]
2026-05-22 docs(labirinto): Parede externa correta
    Desconsiderar o outro documento
    [Parede_externa_8.FCStd]
2026-05-22 docs(labirinto): Parede interna 8
    Parde interna: 165 mm por 50 mm de altura + pinos de 12 mm para piso
    [Parde_interna8.FCStd]
2026-05-22 docs(skid): Skid 2.0
    Arquivo CAD do skid redimensionado sem furos.
    [Skid_2.0.FCStd]
2026-05-22 Carcaça superior remodelada
    [Chassi_superior3.1.FCStd]
2026-05-22 Adiciona base chassi remodelada
    [Base-3.0.FCStd]
2026-05-23 fix: mudar local de arquivos do labirinto para pasta certa
    [Labirinto06.FCStd]
2026-05-23 docs(cad): adicionar modelos de teste do parafuso m2
    [TESTEfuros1.0.FCStd]
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2026-05-25 ajuste labirito
    [parede_externa_7.step, parede_interna_7.step, piso_8.step]
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2026-05-25 fix: corrige erros de escrita
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2026-05-27 suporte e mancal 3D
    [mancal.step, suporte_bateria.step]
2026-05-28 94 us 10 validação da telemetria recebida (#322)
    * feat: validar dados de telemetria com avisos personalizados pelo backend
    * frontend
    * fix: corrige erro de integração e implementa o toast
    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
2026-05-31 Adicionar Skid 3.0 e 3.1
    ## Descrição
    O skid precisa ser alterado para ficar com uma altura compatível com a roda. De acordo com os cálculos realizados pela equipe, a altura da peça precisava ser alterada para 7 mm. A versão 3.0 não poss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
    [Skid_3.0.FCStd, Skid_3_1.FCStd]
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2026-06-01 docs: add remodelagem do suporte da pcb
    [SuportePCB_2.0.FCStd]
2026-06-01 Revert "Feat: Adição de página de Estados e implementação de recepção de dados." (#373)
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2026-06-01 fix: correcoes do teste da conexao com o web
    [main.cpp]
2026-06-02 fix: resolve conflitos e atualiza pacotes de testes do labirinto e telemetria
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2026-06-03 [US-19]: Consulta Geral de Todos os Labirintos (#379)
    * feat: adicionado nova rota para retorno de corridas
    * feat: criação do frontend para consulta de corridas
    * fix: ajusta botões do navegador
    * fix: troca a ordem dos endpoints
    * fix: remove componentes desnecessários
    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
2026-06-03 docs: add novo modelo da roda
    [Roda-1.0.FCStd, Roda-1.1.FCStd]
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2026-06-03 fix: corrige visualizaçao de codigo
2026-06-03 Upload assembly com peças para não acusar erro
    [Assembly-2.0.FCStd, Chassi_superior3.3.FCStd, bateriatemp.FCStd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]
2026-06-03 Refatoração de UI/UX e Padronização do Dashboard de Monitoramento (US-12) (#380)
    * feat: paleta de cores e configuração tailwind
    * refactor: testes do dashboard
    * feat: troca cores e layout style
    * fix trajetoria e renderização logica.
    * fix conflitos
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2026-06-04 docs(assembly): adicionar assembly do labirinto
    [Assembly-2.0.FCStd, AssemblyLabirinto1.FCStd, Chassi_superior3.3.FCStd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]
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2026-06-05 docs: PCB versão definitiva
    Documentos da versão definitiva da PCB, contendo imagens, arquivos 3D e 2D e arquivos para a fabricação
    [3D_PCB2_2026-06-05.step, BOM_Board1_Schematic1_2026-05-11.xlsx, BOM_Logic & Control Board_PCB_2_2026-06-05.csv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]
2026-06-05 refactor: rework completo da saloção do labrinto
    [main.cpp]
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2026-06-05 fix: versionamento de desenhos técnicos dos suportes
2026-06-05 fix: ajustes gerais na estrutura do diretório de drafts
2026-06-05 docs: add modelo 3D do motor
    [motorN20.FCStd]
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2026-06-08 fix: Adição do plano de GND nas duas camadas
2026-06-08 docs(labirinto): adicionar novas medidas do labirinto no draft
    [ParedeInternaDraft9.FCStd, PisoDraft9.FCStd, paredeexternaDraft9.FCStd]
2026-06-08 colocado os desenho tecnicos skid e suporteMotor
    [Assembly-2.1.FCStd, Roda-1.1.FCStd, motorN20.FCStd]
2026-06-10 refatoracao da Página de Análise de Corrida (#426)
    * refatoracao do sistema de mapeamento e melhorias na interface do labirinto
    - centralizacao da logica de sinal de telemetria no hook useTelemetria
    - implementacao do componente CorridaDetailOverlay com visualizacao responsiva
    - criacao da pagina HistoricoCorridasPage com filtros e visualizacao detalhada
    - correcao de erros de lint e loops de renderizacao nos componentes MazeViewer e DashboardIndicadores
    - atualizacao da suite de testes unitarios e de integracao para refletir as mudancas na interface
    - melhoria na responsividade do labirinto com suporte a scroll personalizado e escalonamento automatico
    * resolve conflito do teste de inte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
2026-06-10 refactor: remove botões inativos da barra de navegação (visão geral e configurações) e unifiquei as páginas duplicadas de labirinto e monitoriamento.
    [Assembly-2.0.FCStd, Chassi_superior3.3.FCStd, bateriatemp.FCStd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]
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2026-06-11 fix: corrige arquitetura de tasks para nao travar a navegacao
    [partitions.csv]
2026-06-12 fix: novo modelo do suporte da pcb
    [SuportePCB_2.1.FCStd]
2026-06-12 fix: novo modelo do suporte do motor, e drafting do mesmo
    [SuporteMotor1.1.FCStd]
2026-06-12 fix: novo modelo de suporte do sensor
    [SuporteSensor4.0.FCStd]
2026-06-12 refactor: ajuste de estrutura no repositório de cads e drafts
    [Base1.0.FCStd, Base2.2.FCStd, Base2.4.FCStd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]
2026-06-12 refactor: add blackboxes atualizadas das pcbs na pasta de estrutura
    [bateria_2.0.FCStd, motorN20_1.0.FCStd, pcb_baixo_1.0.FCStd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]
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2026-06-16 fix: botao em alto
    [botoes.cpp]
2026-06-18 docs: add novas blackboxes
    [espacadorM2x8.FCStd, pcb_baixo_1.0.FCStd, pcb_baixo_1.2.FCStd]
2026-06-18 docs: add suporte da pcb 2.2
    [SuportePCB_2.2.FCStd, pcb_cima_1.1.step]
2026-06-18 docs: add novos modelos do skid e da base
    [Base3.1.FCStd, Base3.2.FCStd, Skid_3.2.FCStd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]
2026-06-19 docs: add assembly 2.2
    [Assembly-2.0.FCStd, Assembly-2.1.FCStd, Assembly-2.2.FCStd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]
2026-06-19 fix: ajuste de furo e nome de pasta
    [Assembly-2.0.FCStd, Assembly-2.1.FCStd, Assembly-2.2.FCStd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]
2026-06-20 docs: add blackbox do sensor frontal e nova versão do suporte dos sensores
    [Base3.2.FCStd, SuporteSensor4.1.FCStd, sensor_VL53L0X.FCStd]
2026-06-21 docs: add sensores e novo suporte ao assembly
    [Assembly-2.2.FCStd, Base3.2.FCStd, RodaPneu-1.1.FCStd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]
2026-06-22 fix(tests): Refatora os testes do componente de Estados dentro da página de Telemetria
2026-06-22 92 us 08 recepção de dados do micromouse (#446)
    * feat: Validação dos dados
    * fix(telemetria) corrige alguns bugs pequenos de telemetria
    * fix(telemetria) corrige alguns bugs pequenos de telemetria
    * ajuste dos testes
    * fix: corrigindo o erro do ACK
    * fix: corrigindo o erro do ACK
    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
2026-06-22 fix: sensores tof, labirinto e mock do ina
    [battery.cpp, main.cpp, pins.hpp]
2026-06-23 docs: add suporte pcb 2.3, suporte bateria 2.0 e base 3.3
    [Base3.3.FCStd, SuportePCB_2.3.FCStd, sup_bateria_1.0.step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]
2026-06-24 fix: ajuste de peças
    [Base3.3.FCStd, RodaPneu-1.1.FCStd]
2026-06-24 docs: novo modelo do skid para deslize invertido
    [Skid_3.4.FCStd]
2026-06-25 docs: add assembly com as peças mais recentes (sem joints)
    [Assembly-2.3.FCStd, Base3.3.FCStd, RodaPneu-1.1.FCStd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]
2026-06-29 docs: add novos modelos para capa do chassi
    [chassi_superior1.0.FCStd, chassi_superior5.0.FCStd, chassi_superior5.1.FCStd]
2026-06-29 docs: add chassi superior 5.1 ao assembly
    [Assembly-2.3.FCStd, chassi_superior5.1.FCStd]
2026-06-29 fix: ajuste de furos no chassi superior 5.1
    [Assembly-2.3.FCStd, chassi_superior5.1.FCStd]
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2026-07-01 docs: arquivos da PCB da versão definitiva
    [BOM_Motor & Drive Board_PCB1_2026-06-30.csv, BOM_Motor & Drive Board_PCB_1_2026-06-05.csv]
2026-07-01 fix: corrje bug de renderização de paredes na rota otimizada no corridadetail.
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2026-07-06 docs: add modelo do chassi superior 5.2 (cad e assembly)
    [Assembly-2.3.FCStd, chassi_superior5.1.FCStd, chassi_superior5.2.FCStd]
2026-07-07 fix: mudanças na lógica da corrida
    [battery.cpp, pins.hpp]
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2026-07-08 fix: correcao do ajuste do micromouse durante a navegacao
    [teste_navegacao.cpp]
2026-07-08 docs(draft): adicionar skid 4.1
    [Skid_4.1.FCStd]
2026-07-08 docs: add modelo do chassi superior v5.3
    [chassi_superior5.3.FCStd]
2026-07-08 refactor reorganizar versionamento dos assembly's
    [Assembly-2.3.FCStd, chassi_superior5.1.FCStd, chassi_superior5.2.FCStd]
2026-07-08 docs: add assembly 2.4
    [Assembly-2.4.FCStd, Base3.3.FCStd, RodaPneu-1.1.FCStd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]
2026-07-08 fix: correções de bias
    [teste_navegacao.cpp]
2026-07-08 fix: flood fill ignorando caminhos nao explorados
    [teste_navegacao.cpp]
2026-07-08 fix: ajuste na contagem por tile
    [teste_navegacao.cpp]
